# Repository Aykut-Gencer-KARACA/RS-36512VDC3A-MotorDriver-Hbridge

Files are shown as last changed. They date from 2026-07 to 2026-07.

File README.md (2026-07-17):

# H-Bridge Motor Sürücü — RS365 12V DC 3A
### LM2596S-ADJ DC Step-Down Regülatörlü Çift Yönlü ve Hız Kontrollü Motor Sürme Projesi

Bu projede, bir önceki projemde kullandığım **RS365 serisi 12V DC / 3A** motor ailesini, bir **H-Bridge** yardımıyla **çift yönlü** ve **hız kontrollü** şekilde sürdüm. Güç tarafında ise +24V DC kaynaktan **LM2596S-ADJ** ile 12V seviyesine düşüş sağlayan bir step-down regülatör tasarladım.

---

## 📋 İçindekiler

- [Regülatör Tasarımı](#-regülatör-tasarımı)
- [H-Bridge Yapısı](#-h-bridge-yapısı)
- [PWM Sinyal Üretimi](#-pwm-sinyal-üretimi)
- [Karar Birimi](#-karar-birimi)
- [Gate Driver Kullanımı](#-gate-driver-kullanımı)
- [Devre Görselleri](#-devre-görselleri)

---

## ⚡ Regülatör Tasarımı

+24V DC gerilim kaynağından, **LM2596S-ADJ** entegresi ve hesaplanan **feedback dirençleri** vasıtasıyla çıkış voltajını **12V** seviyesine düşürdüm.

### İndüktör Seçimi
Motor gibi elemanlar yük altında beklenenden fazla akım çekebildiği için:

- Akım sınırı 3A olmasına rağmen, yük üzerindeki **ripple etkisini azaltmak** amacıyla kullanılan sabit değerlikli indüktörün çalışma akımını **4A** seçtim.
- Öngörülemeyen sonuçların önüne geçmek için satürasyon akımını **I<sub>SAT</sub> = 4.5A** olarak belirledim.

### Çıkış Kondansatörleri
Motorun ani akım çekiminde çıkış geriliminin çakılmaması ve Lenz kanunu gereği hat boyunca oluşacak hipotetik endüktans geriliminin yük üzerindeki gerilim stabilitesini bozmaması için:

- **Seramik kondansatörler** → Hızlı tepki gereken anlar için, çıkışa en yakın konumda
- **Düşük ESL değerlikli polarize kondansatörler** → Süreğen voltaj düşüşleri için

### Giriş Kondansatörleri
LM2596S-ADJ datasheet'inden, anahtarlama anlarındaki ortalama akımın **0–2A** arasında değiştiğini ve anahtarlama süresinin **30–50 ns** olduğunu öğrendim. Bu bilgilerle:

1. Güç kaynağından çekilecek **Coulomb miktarını** kağıt üzerinde hesapladım.
2. İzin verilen voltaj düşüşünü **%6** kabul ederek formülize ettim.
3. Girişteki ani akım ihtiyacını karşılayacak kondansatör gruplarını, çıkıştakilerle aynı mantıkla konumlandırdım.

---

## 🔀 H-Bridge Yapısı

H-Bridge'lerin mantığı, basit bir anlatımla, her yön (veya her faz bağlantı noktası) için **iki adet MOSFET** kullanıp bunların gate'lerini anahtarlayarak akım geçişine izin verme prensibine dayanır.

### High-Side: P Kanallı MOSFET'ler
Güç tüketimini azaltmak amacıyla high-side switch tarafında **P kanallı MOSFET'ler** kullandım:

- Gate bacağına **0V (pratik olarak GND)** verildiğinde MOSFET açılır ve Source → Drain yönünde akım geçişine izin verir.
- Kullanılmadıkları anlarda kapalı kalmaları için gate bacaklarını **pull-up dirençleriyle** regülatör çıkışından besledim.
- Bu sayede kısa devre yapmadan, miliamperler mertebesinde akımla gate'teki hipotetik kondansatör dolar; Drain–Source kanalı elimine edilerek akım geçişi sızıntı seviyelerine düşer.

### Low-Side: N Kanallı MOSFET'ler
Motor hız kontrolü için akım geçişini **PWM** ile sınırlandırdım:

- PWM sinyallerini **N kanallı low-side MOSFET'lerin** gate bacaklarına uygulayarak motor hızını kontrol ettim.

---

## 📶 PWM Sinyal Üretimi

Bu tarz projelerde PWM sinyalleri genellikle dijital devrelerle üretilir ve frekans yazılımla ayarlanır. Ancak ben bu işi **tamamen analog** çözmek istedim:

- **LM555** entegresini **a-stable modda** çalıştırarak bir kondansatörü V<sub>CC</sub>'nin **1/3'ü ile 2/3'ü** arasında doldurup boşalttım.
- Kondansatörün kapasitans değeri frekansa direkt etki ettiği için, datasheet'teki **periyot formülünden** periyodu, oradan da frekansı elde ettim.
- Motorun tekleme seslerinin insan kulağıyla duyulmaması için **~20 kHz** bandında frekans sağlayacak bir kapasitans seçimi yaptım.

---

## 🎮 Karar Birimi

Motorun dönüş yönüne karar veren mekanizma olarak bir **anahtar** kullandım.

Anahtar çıkışı, **AND** ve **NOT** kapılarından geçirilerek hem P kanallı hem de N kanallı MOSFET'lerin gate bacaklarını sürecek şekilde konumlandırıldı.

---

## 🚀 Gate Driver Kullanımı

Herhangi bir kondansatör boş durumdayken hipotetik olarak **kısa devre** gibi davranır. Bir MOSFET'in gate bacağı da aslında bir kondansatörden ibaret olduğuna göre, gate'i açmak nanosaniyeler içinde **~1.5A** akım çekilmesi demektir.

Bu yüksek anlık akım AND ve NOT kapılarıyla sağlanamayacağı için:

- Beslemesindeki **seramik kondansatörler** sayesinde girişindeki akımı anlık olarak şoklayıp onlarca kat yükselten **gate driver entegreleri** kullanıldı.

---

## 📷 Devre Görselleri

Regülatör Devresi

H-Bridge Devresi

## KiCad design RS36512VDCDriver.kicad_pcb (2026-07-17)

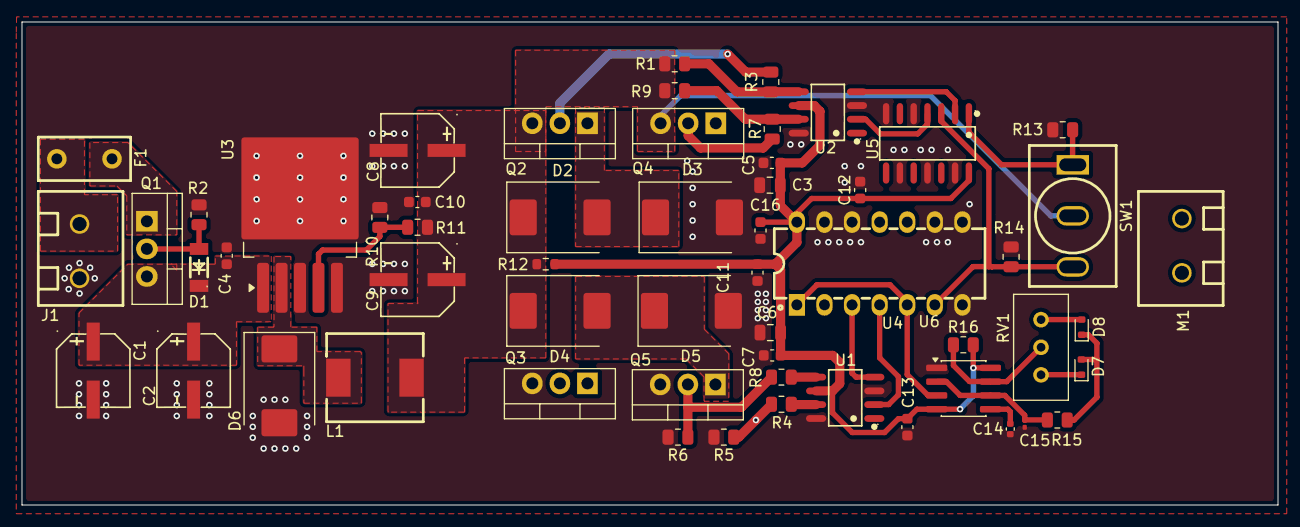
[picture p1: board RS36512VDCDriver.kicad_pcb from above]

Board: 4 copper layers, 115.7 x 44.5 mm, 57 parts (0 on the bottom side), 32 nets.

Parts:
C1, C2, C8, C9: 470 uF 35 V; CAP-SMD_BD6.3-L6.6-W6.6-FD
C3, C6: 4.7 uF 50 V; C_0805_2012Metric
C4, C10: 1 uF 50 V; C_0603_1608Metric
C5, C7, C12, C13, C16: 100 nF 50 V; C_0603_1608Metric
C11: 470 uF 50 V; C_0603_1608Metric
C14: 100 nF 16 V; C_0402_1005Metric
C15: 6.8 nF 16 V; C_0201_0603Metric
D1: Zener 12V; LL-34_L3.5-W1.5-RD-2
D2, D3, D4, D5, D6: 4A Schottky Diode; D_SMC
D7, D8: Diode; D_SOD-523
F1: Fuse 2.5 A; FUSE-TH_L8.5-W4.0-P5.08-D0.6
J1: Screw_Terminal_01x02; CONN-TH_2P-P5.00_MX126-5.0-GN01-02P-CU-S-A
L1: 68 uH 4A ISAT 4.5; IND-SMD_L9.0-W8.1
M1: Motor_DC; CONN-TH_2P-P5.00_MX126-5.0-GN01-02P-CU-S-A
Q1, Q2, Q4: Q_PMOS_DGS; TO-220-3_Vertical
Q3, Q5: Q_NMOS_DGS; TO-220-3_Vertical
R1, R2, R5, R6, R9, R13, R14: 10 K Ohm; R_0805_2012Metric
R3, R4, R7, R8: 100 Ohm 125 mW; R_0805_2012Metric
R10, R15, R16: 1K Ohm 125 mW; R_0805_2012Metric
R11: 9K Ohm 125 mW; R_0805_2012Metric
R12: 10 Ohm 100 mW; R_0603_1608Metric
RV1: 10K Ohm Multiturn; Potentiometer_Bourns_3296W_Vertical
SW1: SW_SPDT_MSM; SW-TH_MT-0-103-A101-M200-RS
U1, U2: EG4427; SOP-8_L4.9-W3.9-P1.27-LS6.0-BL
U3: LM2596S-ADJ; TO-263-5_TabPin3
U4: CD4081BE; DIP-14_L19.4-W6.4-P2.54-LS7.6-BL
U5: CD4069_C3041279; SOP-14_L8.8-W3.9-P1.27-LS6.0-BL
U6: LM555xM; SOIC-8_3.9x4.9mm_P1.27mm

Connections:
/Amplified Gate Driver Four: R7.2, R9.2, U2.7 (OUTA)
/Amplified Gate Driver One: R8.2, U1.5 (OUTB)
/Amplified Gate Driver Three: R1.2, R3.1, U2.5 (OUTB)
/Amplified Gate Driver Two: R4.1, U1.7 (OUTA)
/Gate Driver First: U1.4 (INB), U4.3 (1Y)
/Gate Driver Fourth: U2.2 (INA), U5.4 (2Y)
/Gate Driver Second: U1.2 (INA), U4.4 (2Y)
/Gate Driver Third: U2.4 (INB), U5.2 (1Y)
/IC_Input: C3.1, C5.1, C6.1, C7.1, C11.1, C12.1, C13.1, C16.1, R12.2, R16.2, U1.6 (VDD), U2.6 (VDD), U4.14 (VDD), U5.14 (VDD), U6.4 (~RST), U6.8 (VCC)
/LM555 Pin3 Out: U4.1 (1A), U4.5 (2A), U6.3 (OUT)
/Motor_Input: C8.1, C9.1, C10.1, D2.1 (K), D4.1 (K), L1.2, Q2.3 (S), Q4.3 (S), R1.1, R9.1, R11.2, R12.1, SW1.2 (3)
GND: C1.2, C2.2, C3.2, C4.2, C5.2, C6.2, C7.2, C8.2, C9.2, C10.2, C11.2, C12.2, C13.2, C14.2, C15.2, C16.2, D3.2 (A), D5.2 (A), D6.2 (A), J1.2, Q3.3 (S), Q5.3 (S), R2.2, R5.2, R6.2, R10.1, R13.2, R14.2, U1.3 (GND), U1.8 (SD), U2.3 (GND), U2.8 (SD), U3.3 (GND), U3.5 (~ON/OFF), U4.7 (VSS), U4.8 (3A), U4.9 (3B), U4.12 (4A), U4.13 (4B), U5.5 (3A), U5.7 (VSS), U5.9 (4A), U5.11 (5A), U5.13 (6A), U6.1 (GND)
unnamed: D1.2 (A), Q1.2 (G), R2.1
unnamed: C1.1, C2.1, C4.1, D1.1 (K), Q1.3 (S), U3.1 (VIN)
unnamed: D2.2 (A), D3.1 (K), M1.1 (+), Q2.1 (D), Q3.1 (D)
unnamed: D4.2 (A), D5.1 (K), M1.2 (-), Q4.1 (D), Q5.1 (D)
unnamed: D6.1 (K), L1.1, U3.2 (OUT)
unnamed: D7.2 (A), D8.1 (K), R15.2
unnamed: D7.1 (K), RV1.1
unnamed: D8.2 (A), RV1.3
unnamed: F1.1, J1.1
unnamed: F1.2, Q1.1 (D)
unnamed: Q2.2 (G), R3.2
unnamed: Q3.2 (G), R4.2, R5.1
unnamed: Q4.2 (G), R7.1
unnamed: Q5.2 (G), R6.1, R8.1
unnamed: R14.1, SW1.3 (4), U4.6 (2B), U5.3 (2A)
unnamed: R10.2, R11.1, U3.4 (FB)
unnamed: R13.1, SW1.1, U4.2 (1B), U5.1 (1A)
unnamed: C14.1, U6.5 (CONT)
unnamed: R16.1, RV1.2, U6.7 (DISCH)
unnamed: C15.1, R15.1, U6.2 (TRIG), U6.6 (THRES)
